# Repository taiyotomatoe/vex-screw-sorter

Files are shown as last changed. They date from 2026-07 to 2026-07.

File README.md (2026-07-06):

# Automatic Screw Sorter for VEX Robotics
**An automatic screw sorter, designed for standard VEX screws of sizes 0.25" up to 2.00".**  
*Note: Other screws such as shoulder screws may not work.*

We all hate having to sort our screws manually, and no one puts the screws back in the right place. 

That's why I made this screw sorter, which works **without requiring a human operator** to manually place screws on the sorter - just dump your screws in the box, start the motor, and get it sorted automatically.

### Preview: 

### Features:
- Knob, to control the motor speed
- LCD Screen to display current speed + number 

# Make your own sorter! 
All files needed to build this project are provided in their respective folders. 

### PCB: 
(Kicanvas wouldn't work...) Routing is a bit of a mess. (I'm a noobie at this)




### Firmware: 
Arduinon code

### Bill of Materials
[Link](https://docs.google.com/spreadsheets/d/1GzJbDsBg9s3fJ3GwzlsMUPDhf9ZihwElanYWZgdYd-w/edit?usp=sharing)

- XL4015 DCDC step-down converter
- JGA25-370 DC Reduction Motor with Encoder - 12V, 280RPM
- LCD Blue Screen IIC/I2C 2004 5V LCD Module for Arduino
- Alps EC11E Rotary Encoder
- Arduino Nano Every
- Male to Female Jumper Wire
- 2pcs 902540 3.7V Battery LIPO Lipo Battery 800mAh Battery
- 1.25T-2A: Connector for Lipo Battery
- WAFER-PH2.0-6PWB
- 2.54 Pitch PIn sockets 
- Magnets 5-pack

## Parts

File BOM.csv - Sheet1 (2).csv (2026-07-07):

Item Name | Qty | Price (total) (USD) | Item link | Notes
XL4015 DCDC step-down converter | 1 | $2.66 | https://ja.aliexpress.com/item/1005006127518056.html?gatewayAdapt=glo2jpn#nav-review | For faster shipping, I've ordered a different one.
JGA25-370 DC Reduction Motor with Encoder - 12V, 280RPM | 1 | $5.00 | https://www.amazon.co.jp/-/en/JGA25-370-Reduction-Encoder-Measurement-Strong/dp/B0BBT1Q1L7?th=1 | -
LCD Blue Screen IIC/I2C 2004 5V LCD Module for Arduino | 1 | $4.31 | https://www.amazon.co.jp/KKHMF-LCD-%E3%83%96%E3%83%AB%E3%83%BC%E3%82%B9%E3%82%AF%E3%83%AA%E3%83%BC%E3%83%B3-2004-%E3%83%A2%E3%82%B8%E3%83%A5%E3%83%BC%E3%83%AB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 | -
Alps EC11E Rotary Encoder | 1 | $3.39 | https://www.monotaro.com/p/5019/9653/ | -
Arduino Nano Every | 1 | $3.32 | https://ja.aliexpress.com/item/1005009007048978.html?curPageLogUid=Z3lVB11il7dK | -
Male to Female Jumper Wire | 4 | $1.27 | https://ja.aliexpress.com/item/1005006616309305.html?curPageLogUid=7d3j23TrAWTj | 10cm should be sufficient
# 2pcs 902540 3.7V Battery LIPO Lipo Battery 800mAh Battery | 1 | $8.01 | https://www.amazon.co.jp/-/en/2pcs-902540-Battery-800mAh-Drone/dp/B0GGHPSYZ7 | First time working with batteries - not sure if this is the right kind
1.25T-2A: Connector for Lipo Battery | 2 | $0.01 | https://jlcpcb.com/partdetail/BOOMELE_Boom_Precision_Elec-1_25T2A/C10819 | Assembled by JLCPCB
WAFER-PH2.0-6PWB | 1 | $0.12 | https://jlcpcb.com/partdetail/XUNPU-WAFER_PH2_06PWB/C3029444 | Assembled by JLCPCB
2.54 Pitch PIn sockets - | 1 | $3.33 | https://ja.aliexpress.com/item/1005007987705629.html?curPageLogUid=CK0XiXW3Ev6p | I will buy a quicker shipping option one.
Magnets 5-pack | 1 | $5.58 | https://www.migros.ch/en/product/721586900000 | There are definitely cheaper magnets - These are the ones I have currently. (and fit the dimensions of the design

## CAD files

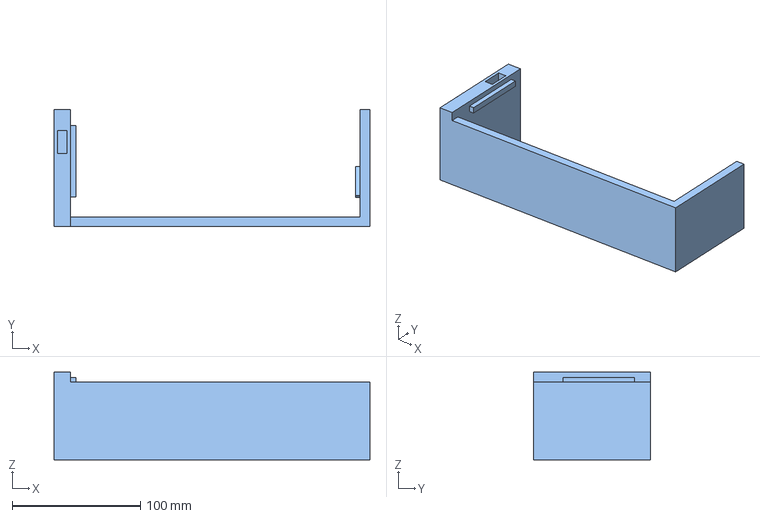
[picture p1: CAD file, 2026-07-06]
CAD/Individual COmpoents/Containers_Outer (4).step
246.4 x 91.4 x 68.6 mm

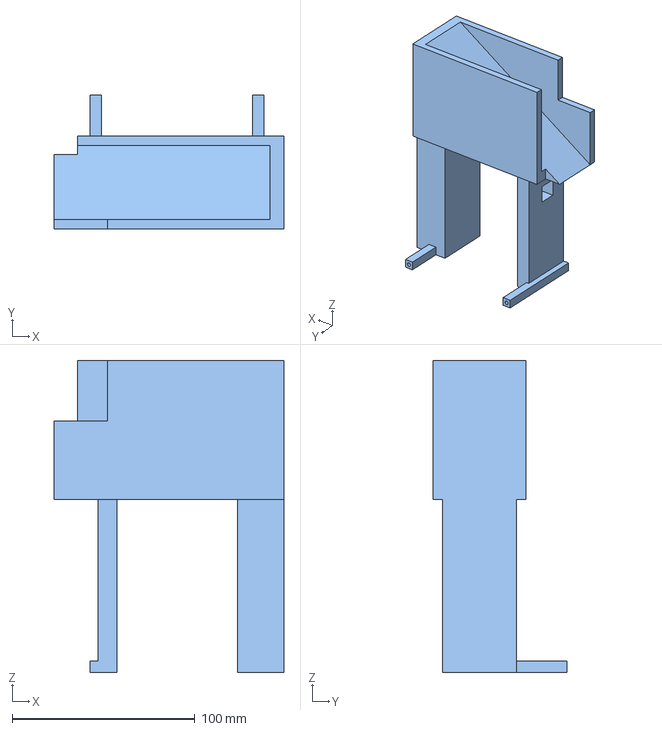
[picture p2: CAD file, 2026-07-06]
CAD/Individual COmpoents/Box.step
125.7 x 73.1 x 170.8 mm

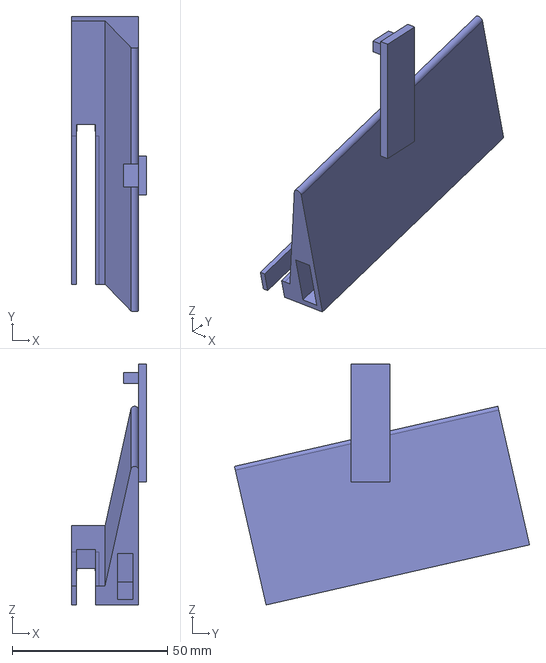
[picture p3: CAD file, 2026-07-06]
CAD/Individual COmpoents/loader_p1.step
24.2 x 95.1 x 77.7 mm

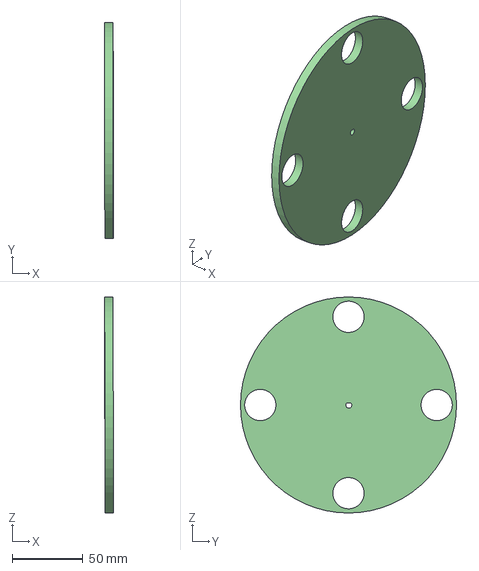
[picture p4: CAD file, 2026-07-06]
CAD/Individual COmpoents/Wheel.step
6.00 x 152.4 x 152.4 mm

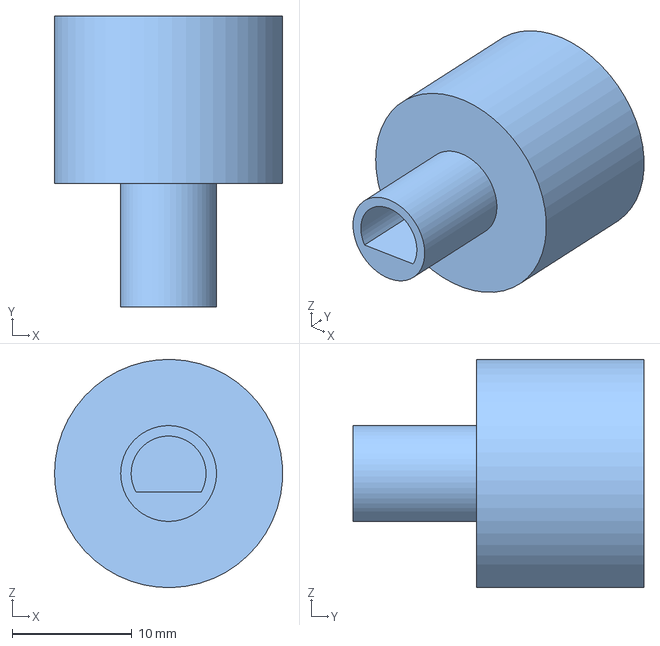
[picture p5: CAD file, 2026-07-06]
CAD/Individual COmpoents/Knob.step
19.0 x 24.3 x 19.0 mm

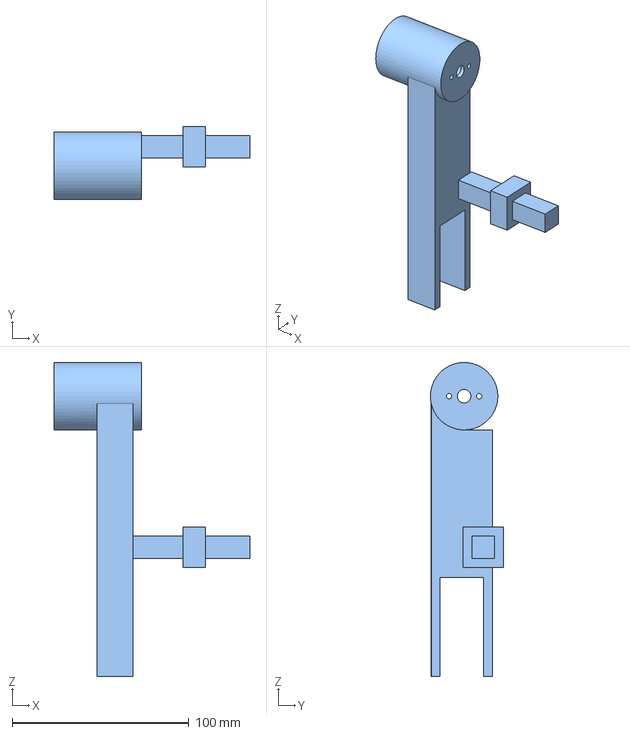
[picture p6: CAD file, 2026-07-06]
CAD/Individual COmpoents/motor holder.step
110.6 x 41.4 x 177.4 mm

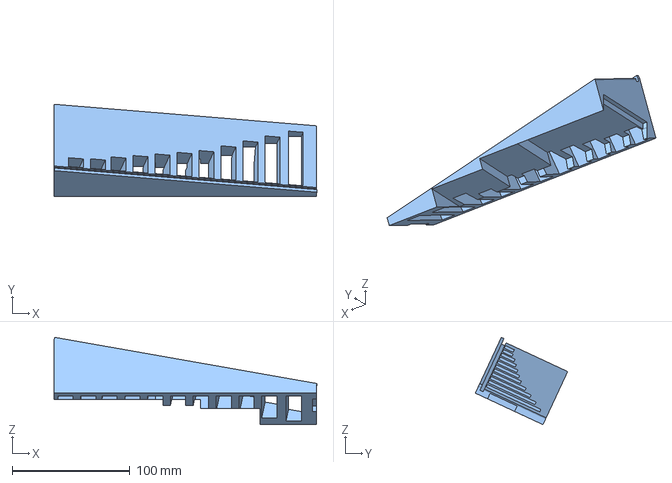
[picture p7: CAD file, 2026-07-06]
CAD/Individual COmpoents/Sorter.step
223.6 x 78.6 x 74.3 mm

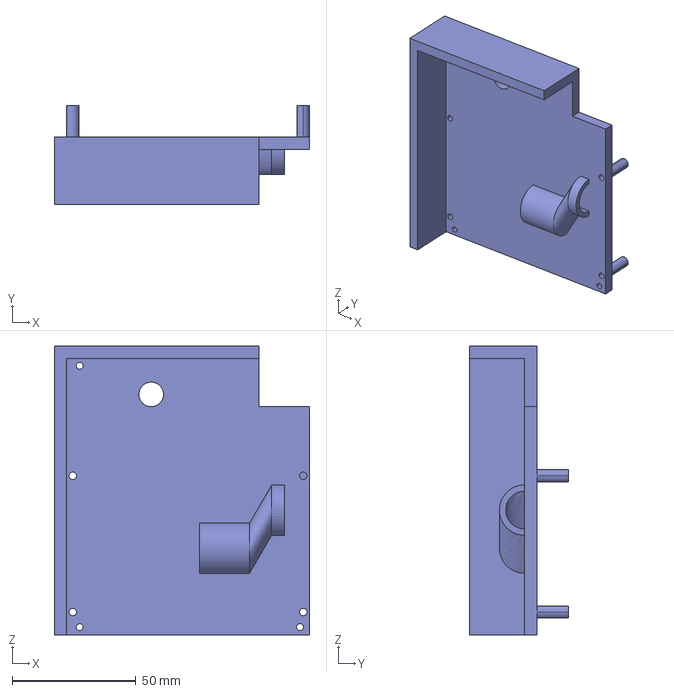
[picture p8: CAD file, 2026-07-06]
CAD/Individual COmpoents/PCB Cover.step
102.9 x 40.1 x 116.6 mm

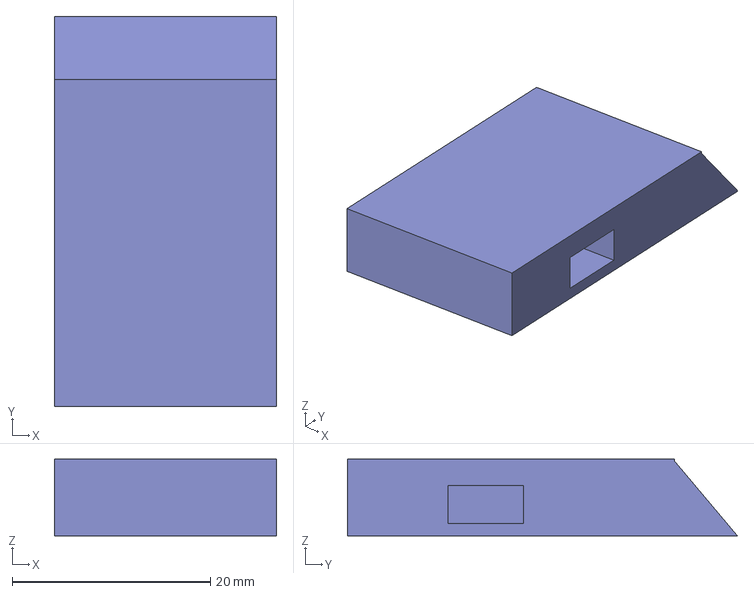
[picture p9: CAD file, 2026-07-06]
CAD/Individual COmpoents/Hook.step
22.5 x 39.4 x 7.76 mm

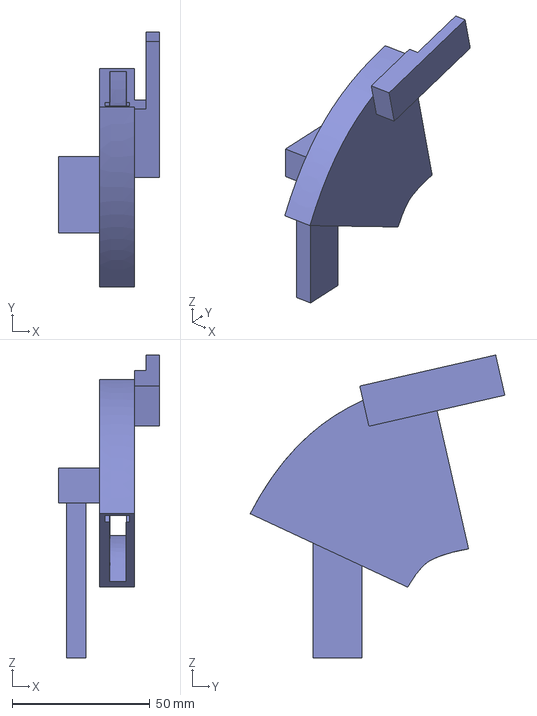
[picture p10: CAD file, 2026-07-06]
CAD/Individual COmpoents/loader_p2.step
36.7 x 92.6 x 110.1 mm

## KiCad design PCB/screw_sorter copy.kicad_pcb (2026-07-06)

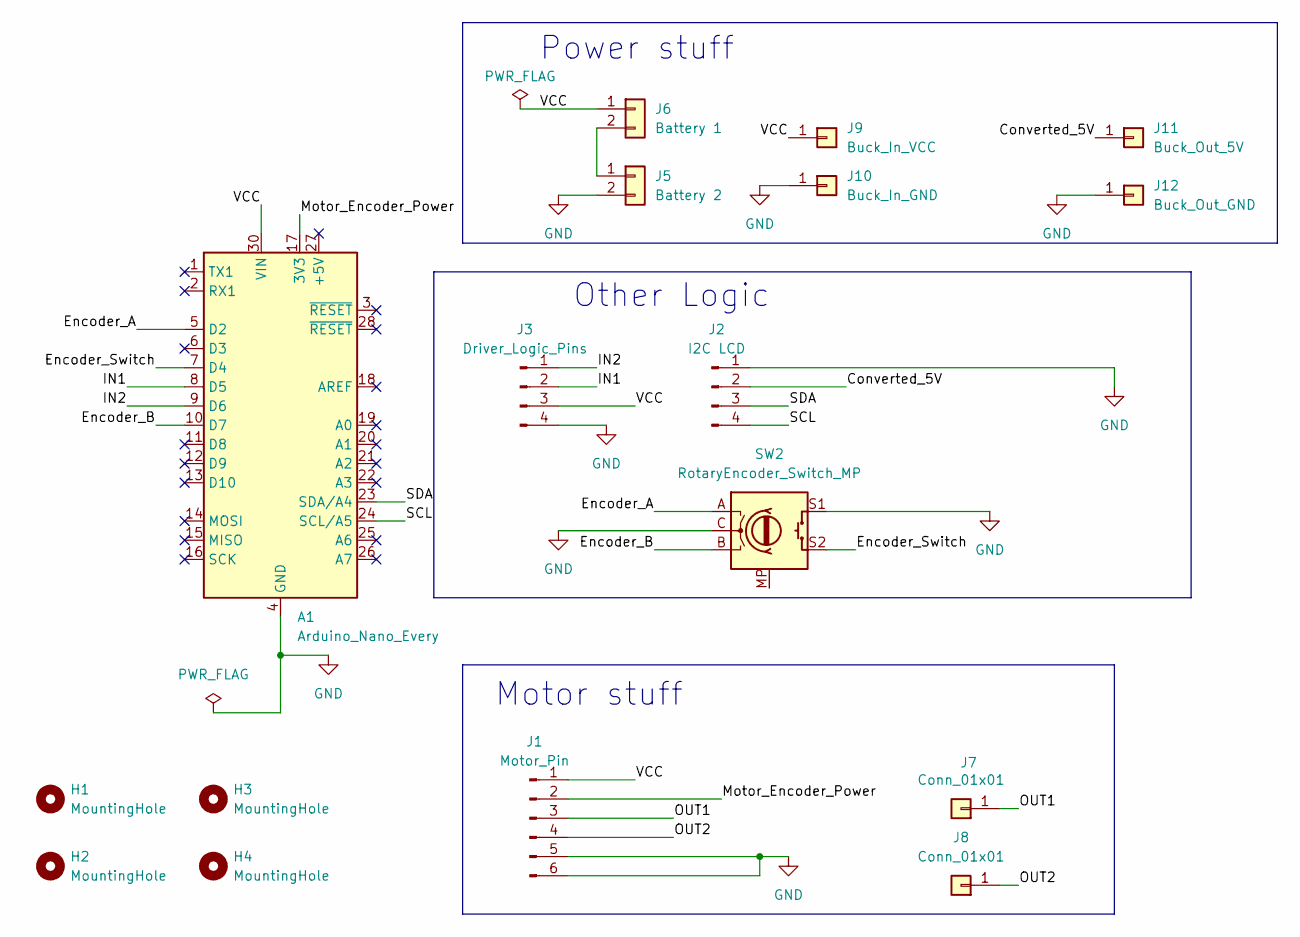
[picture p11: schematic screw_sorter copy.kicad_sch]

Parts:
A1: Arduino_Nano_Every; Arduino_Nano
H1, H2, H3, H4: MountingHole; MountingHole_3.2mm_M3
J1: Motor_Pin; WAFER-PH2_0-6PWB
J2: I2C LCD; PinSocket_1x04_P2.54mm_Vertical
J3: Driver_Logic_Pins; PinHeader_1x04_P2.54mm_Vertical
J5: Battery 2; 1_25T-1-2A
J6: Battery 1; 1_25T-1-2A
J7, J8: Conn_01x01; PinHeader_1x01_P2.54mm_Vertical
J9: Buck_In_VCC; PinHeader_1x01_P2.54mm_Vertical
J10: Buck_In_GND; PinHeader_1x01_P2.54mm_Vertical
J11: Buck_Out_5V; PinHeader_1x01_P2.54mm_Vertical
J12: Buck_Out_GND; PinHeader_1x01_P2.54mm_Vertical
SW2: RotaryEncoder_Switch_MP; RotaryEncoder_Alps_EC11E-Switch_Vertical_H20mm_CircularMoun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

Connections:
/Converted_5V: J2.2, J11.1 (Pin_1_1)
/Encoder_A: A1.5 (D2), SW2.A
/Encoder_B: A1.10 (D7), SW2.B
/Encoder_Switch: A1.7 (D4), SW2.S2
/IN1: A1.8 (D5), J3.2
/IN2: A1.9 (D6), J3.1
/Motor_Encoder_Power: A1.17 (3V3), J1.2
/OUT1: J1.3, J7.1 (Pin_1_1)
/OUT2: J1.4, J8.1 (Pin_1_1)
/SCL: A1.24 (SCL/A5), J2.4
/SDA: A1.23 (SDA/A4), J2.3
/VCC: A1.30 (VIN), J1.1, J3.3, J6.1, J9.1 (Pin_1_1)
GND: A1.4 (GND), A1.29 (GND), J1.5, J1.6, J2.1, J3.4, J5.2, J10.1 (Pin_1_1), J12.1 (Pin_1_1), SW2.C, SW2.S1
unnamed: J5.1, J6.2

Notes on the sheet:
Motor stuff
Power stuff
Other Logic

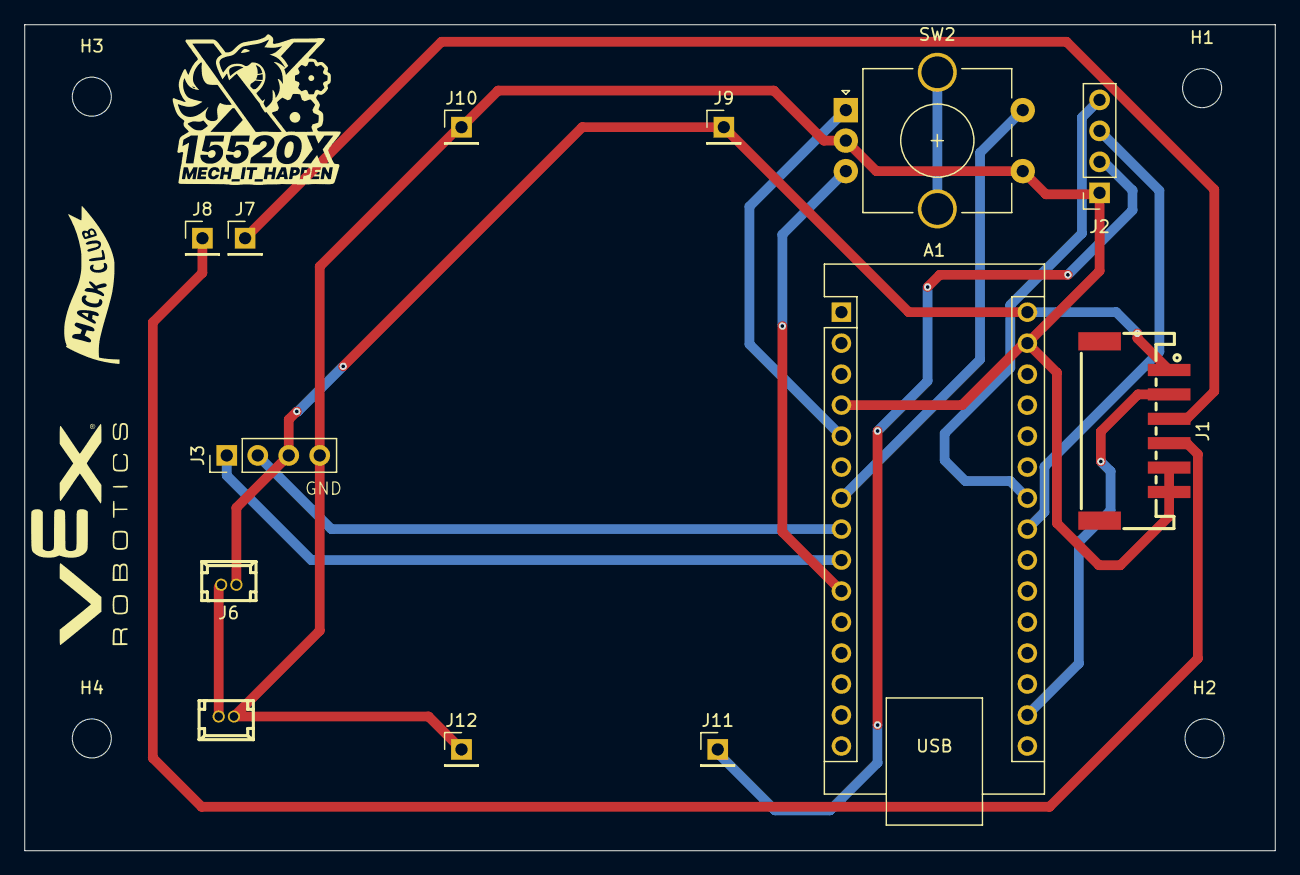
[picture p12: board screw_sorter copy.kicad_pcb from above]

Board: 2 copper layers, 102.5 x 67.7 mm, 17 parts (0 on the bottom side), 14 nets.

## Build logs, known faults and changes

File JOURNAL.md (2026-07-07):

# Devlog: 
**11h worth of work was done on Fallout. (I didn't submit there, as I didn't finish the project.)
More accurate time logs on Lapse/Hackatime.
Fallout Journals are under the journals I did for outpost.** 
### I also had to transfer the images from fallout... I did this manually so it may look messy at times

# 3 July: 
Finished the schematic... 

I finalized the list of the main components for the PCB: 
Rotary Encoder (leftover. from Blueprint)
LCD 
12V Motor (with encoder)
Arduino Nano. 

I found out that I most likely shouldn't power tehse components with the arduino's power pins, so I did some research on voltage converters: 
buck converter vs linear regulator.. .

I also had to do some digging around to find the pin headers for the motor. This motor is one my school had lying around, and has a 2.00mm pitch. I decided to have this assembled by JLCPCB. 
I had difficulties finding a suitable footprint/3d model for these components, so I found the JLCImport plugin, which made my life so much easier by letting me import footprints from within KiCad.
JLCImport Plugin 
(yes I could've just used the default KiCad ones, but this also applies to other components/projects)

I also need to find a suitable battery to power this project. It could be done using either. a LiPo battery or a power bank. I will do further research on this. 

#2: 
Went back to the CAD. I have to fix an issue on the main sorter where the bigger screws would slide off the bottom - Hopefully by making the part the screw body rests on a bit lower, there should be less bumps to throw the screws off course. 
I also need to change the wheel a bit, so that the magnet fits well - I think it was too wide, but I don't have any calipers with me - I will test this while the thing is printing and stop it when fit. 

I realized I made another dumb mistake, and wasted some more filament. I printed a "testing" patch to waste less filament, with 5 different sizes, so I could see which one would work best, before printing the actual wheel *again*. 

I'm trying to think of ways to secure these two in teh same posiition relative to the sorter each time, but I'll have to test this once it's printed. 

Back to electronics research - not really sure whether the DRV8833 that I'm planning on using for motor control is suitable, because my motor's stall torque is 2A and the DRV has a max current rating of 1.5A. I'll test this out. 

A friend suggested using the DRV8871 instead, which seems to be the better option. 

#3/4: Tested out the new wheel thicknesses, and I have a size that alows the magnet to be friction fit well. I will print this final version now. 

I also decided on a [lipo batery ](https://www.amazon.co.jp/-/en/Battery-Rechargeable-Terminal-Bluetooth-Electronics/dp/B0G2MJ5YLF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)
and addded it to the circuit.  

I'm wondering if I can/should power both the arduino and the motor directly from the battery, as I'm worried of a current spike or something when the motor starts spinning. 

Time spent (total for today): 3h30

# 4 July

Looking at the buck converters, I just cannot find the footprint for them. I think what I'll do is I'll estimate the destance between the pins, and then bend the pins on the pcb when soldering the buck converter on. (unless someone warns me to do otherwise)

For this one, I'll go with 21mm and 52.7mm apart. 

Time spent: 1h50

# 5 July: 

I'm reprinting the sorter again - hopefully printing it the other way will make it work better. It seeesm that printing the sorter upside down makes the face less smooth because of the supports, which makes it work less. 

I'm also just going to use the 3d model to space out the buck converter pins out correctly. Hopefully this is a precise enough method. 
I think this turned out ok. This better work.. 

I've been running into more issues to do wiht pin spacings and not finding their values anywhere, and I'm slwoly makign progress. I've been measuring the 3d models that I found of the components, so the pin distances shoudl be correct, assuming the 3d models were correct. 

I think I have the layout I want (haven't done the routing yet), and I will import this into Fusion and design an enclosure for it. 
This is the idea for now: 
I am slightly worried that the potentiometer will be difficult to control because of its position as well as the plastic used to support it being light and probably prone to sliding around. I might change the pcb just to make the potentiometer higher up, depending on costs, and I'll experiment with the box as welll to make it less prone to sliding around. 

I made a little mistake not setting the clearances before routing the traces... Hopefully the clearances I calculate aren't much more than what I currently have. 
Looks like it's fine. 
I moved onto adding graphics on the silkscreen, then realized all my 3d models were gone, for some reason... 
Back in business. 

Time spent: 3h30

# 6 July: 

#1: 
To make it easier for the user to turn the rotary encoder, I think I should make a knob for it. 

#2: 
Wrote some code for the LCD screen that'll be used. The encoder code should work, I already worked on it a month ago. 
I used the map function to map encoder values to 0-155, because I don't want the motor spinning at full speed (255). 
I also learnt how the I2C comm works, and that it's a form of serial communication alongside UART (the one I was familiar with), and  others. 

#3/4: 
Some more work on the CAD - changing hole sizes to fit better... etc
Rendered the Screw Sorter - the final printed verrsion probably won't look as vibrant, but I think it looks alright for now. 

Time spent: 2h55

# automatic Vex screw sorter — Journal Export

- Exported at: 2026-07-07T04:16:02Z
- Project ID: 1106
- Entries: 8

## Entry 1
- ID: 8177
- Author: tomato
- Created At: 2026-05-20T16:42:01Z

### Content

(logging this 3 days later, was busy) 
this is my first journal, which will also serve as part of the readme, because I’m writing my idea of what this project will look like. I did previously work on this project without logging it, but I have many more improvements to make - I’ll mention the first one in a second. 

In Vex robotics, we all use screws. However, it’s easy to throw the screws we didn’t use into a random box and forget about putting it bac where it was. 

My screw sorter is an automatic solution to this problem - just dump all your screws in a box and it’ll automatically sort them by size. 

Other designs sort the screws, but still require a human operator to manually put the screws in place. Example: 


my goal for this project is to make the process fully automatic. 
It will use: 

- dc motor, (battery)
- switch to turn it on and off,
- and other features i decide to implement down the line.

I might make a custom pcb for it if I decide to add more parts/to make it look nicer. 

This design by Christopher looks interesting, using magnets to pull the screws up from the box. 


I already have the bottom "sorting part" - made previously. 
The way it'll work is that the screws in the box area will get picked up by the wheel, which has magnets inside. This will then bring it up to the dispenser part, where it'll be directed into the sorter area. 
I am thinking about what would happen if a long screw comes along and it’s upside down. 
I've also found it difficult making a box design that doesn’t interfere with the wheel. 


I also need to make the box inclined so that the screws bunch up near the bottom of the wheel. 

I added a “hook” which would theoretically detach the screw from the magnet (i also made the hole for it)
and a cover to keep it from falling out. 
In hindsight I don’t think the “hook” needs to be shaped this way.




there is a rail for the screws to slot into place in the round part. 

tomorrow, I will (NOT BECAUSE I WAS TOO BUSY)
- work on making the box work,
- attach the new parts (the hook and the cover are currently floating)
- add a shaft/mounting hole for the wheel to spin

### Recording Links

- https://lookout.hackclub.com/api/media/9636e65d-2c7b-4c0e-94a6-4ae4e1f16784/video.mp4

## Entry 2
- ID: 9653
- Author: tomato
- Created At: 2026-05-27T13:32:42Z

### Content

today, I mainly focused on the box part. 
previously, the box was just a flat box, so once there weren’t enough screws, the magnets wouldn’t pull the leftover screws that were too low or too far to get picked up. 


I therfore made the box inclined, so the screws would naturally tend to the wheel. 

I also had to maek sure that it wouldn’t interfere with the other parts of the sorter and hit other screws. 



i then realized how dumb i’d been to just have a box enclosing the whole thing: the screw would just get stuck inside. 🤦




I therefore made a slit for the screw to go through. 
this may cause rpoblems down the line, wiht screws falling out from the slit, especialy the smaller screws, but I want to test this version first and then come up with solutions. 

NExt I worked on teh hook a little bit, making it a bit less complicated. 
i also attached as one body like this, although I mgiht need to make some changes when printing this as i can foresee the need for some supports. 
I’ll go for this for the moment because I want to test this section, without having to figure out a complicated mechanical attachment system (That’d be more efficient/refined, so work for another day)


this is the current result. 


i also did some cleaning up, renamign the bodies. 
I should rename the sketches one day too.  


the takss now are: 

- make a drive shaft hole in the wheel, (+ an attachment) so that the wheel can be spun by a motor 
This’d allow me to test the loading section (fig.the image above)
I will test this on a breadboard for the moment, I am also considering implementing other components on a PCB.
- make a support for the box (it cant float unfortunately)
- figure out a support for the main sorter: 
I previously had a design which worked, but it was a bit clunky and required some taping. 
I will therefore rework this.



I also want to learn how to deal with sketches in fusion360, such as when I insertt a new component and then want to edit a previosu sketch with the new component in mind: (the new component doedsnt show)

I wasn’t able to find an answer, and I have asked some of my teachers.

[Continued on the next day, 26 May]: 

I briefly worked on the README, learnt a bit about how to use Markdown. 
I need to find what motor I’ll be using, so that I can: 
1. Put it in the 3d model and design accordingly
2. (Order if needed); assemble the circuit for testing (RPM shoudln’0t be that fast)

Otherwise, I improved the body separation for the loader. This allows the parts to be tested individually, saving on filament/time. 
To attach the hook, I created a hole and will fit a bar into it, as seen in the images below. 
I also incorporated tolerances, which I will need to test as well. 











Below was my first idea at attaching the curved part with the first part of the funnel. 
This won’t work, and my current solution I have in mind is: 
hot glue the parts together
however this will make testing more inconsitent/harder in my opinion, so I will figure out a better way tomorrow. 





I also need to think about how to attach the motor to the wheel, as there are many parts around that miht interfere with the motor attachment. 

That’s it for today (and yesterday), next time (tmr hopefully) I will: 
figure out the body attachment methods
do some research on the motors/start designing the pcb???
3d print soon

### Recording Links

- https://lookout.hackclub.com/api/media/746643bf-e4d1-42b6-8ecd-86335d50c0c6/video.mp4
- https://lookout.hackclub.com/api/media/720516d4-a807-4749-aefb-02b7c3763dcb/video.mp4
- https://lookout.hackclub.com/api/media/73e45309-c194-4816-9717-e51777492c30/video.mp4

## Entry 3
- ID: 10525
- Author: tomato
- Created At: 2026-05-30T21:47:17Z

### Content

### 30 MAY: the loading part has been printed and is being tested! 

Firstly, I added some supporting pillars for the box. This can however be replaced by a book or something for testing. 


i also found a DC motor to use - it’s just a 12V motor that I have lying around at the moment - that’d be the easiest to use for now. I make the shaft hole for it in the wheel. 

I should, in the future, allow the wheel to be attached to the box, so the distance stays constant (easier for end user)
But I will do this after I figure out what other parts I need and where to put them, like the battery and cables.. 




The sorting part requires the main sorter and the containers that will store the screws after they’re sorted. image: 



the mian challenge was having the containers not hit the screw sorter, as the top sorting bit has to be slanted to work properly (the screws tend to get stuck if it’s not inclined)

I first made the other slot for the screw sorter to be held in place. 





I had to make some minor adjustments here to make sure the sorter would hold in place, using the cross-section analysis tool in Fusion. 

But then I realized I could extend this hole so that it goes further down, giving the containers more space. 

This wans’t enough for the containers, however, so i redesigned them (based off the projections of the old design) to fit more nicely with the main sorter. 





The sorter, along with the containers, are now ready to be printed. I’ll only print one for now to not waste too much filament. 

**[SECOND Recording]**
I came back and worked on the wheel. I firstly added a holder for the motor. 



The wheel should be at a set distance from the box, so that it works well; 
The obvious solution is to. have the box and wheel be one big body. 
However, I want to keep the parsts of this project modular, so that they can be 
a. printed easily
b. tested easily individually. 

Therefore, I thought of making the wheel part attach onto the box, like this. 
I now realize that this will probably cause the motor to fall over in the direction of the wheel, due to the weight of the motor. I can, however, just put a book under to keep it balanced. 



I also attempted to run some stress tests (simulations) on the system, to test the durability, especially of the shaft that holds the motor holder and the box together. 
However it turns out it’s a bit complicated, and 3d printers don’t completely fill up the bodies with filament anyways, so it’d be underweight by a percentage. therefore running tests, even if i could, would most probably overestimate the strength of this part. I’ll try the simulation feature out one day on another project. 


NExt I decided I want to test the loader part. I made it so that the loader can slot into the sorter holder, so that I can test it individually. 





I also split up the loader into two parts, so I can test those individually, and added a coupling attachment. 



I am now going to test these parts of the system, and hopefully they work! 
the last step is 3d printing them, for which I luckily have a 3d printer for at school. I put the file into bambustudio and I am now going to wait ~3 hours for this to print. Hopefully it works! ~~(Now time to stop procrastinating and do my homework…)~~


**[3rd recording]**
So I spent some time testing the loading mechanism that I printed off. Despite some difficulties when removing the supports that came with the print, resulting in me cracking a bit of the plastic, it seemed to work well. 
The screws occasionally require a little nudge, but I can tolerate that for the moment. I haven't tested the first stage yet, as I didn't print it. 

I tested this using the old screw sorter design that I had worked on previously to fallout - it's a bit different, thus why the screws are falling out in the image - the new version should be better. 
I already know that the sorter works, so I won't be prioritizing its testing, yet. 
IMG_3743.HEIC
**Screws were getting stuck due to the printer support filament being hard to remove fully. **
IMG_3739.HEIC

[4th Recording]
I also printed the first stage of the loader. This is when I realized how small the parts physically are, compared to what they looked like in the CAD. I will pay more attention to this n the future. 
IMG_3747.HEIC

I therefore added 2 things to the design of the motor holder: 
- More support for the motor holder
- A stopper so user can attach it to the box easily



### Recording Links

- https://lookout.hackclub.com/api/media/35a3cb54-dcf8-4e49-94c5-097720b6a71f/video.mp4
- https://lookout.hackclub.com/api/media/59da71e0-00d0-4ba8-af40-d77a6ec7c561/video.mp4
- https://lookout.hackclub.com/api/media/ad360f85-8680-47f5-b002-0fccaf02da5a/video.mp4
- https://lookout.hackclub.com/api/media/3a4a85cf-fa2a-4836-8156-b03425d2ca2f/video.mp4

## Entry 4
- ID: 10527
- Author: tomato
- Created At: 2026-05-30T21:54:26Z

### Content

**[From 27 May - Wasn't logged for some reason]**

I started this screw sorting project before fallout. Therefore I already had some designs (which I wasn't completely satisfied with) started. To further integrate each body within the system, I decided to bring over the holder for the screw sorter, so that I could attach other parts of the whole system to it. 

It's basically just a rectangular holder for the actual screw sorter body. 

I didn't take screenshots but I had difficulties with extruding (removing) some of the old parts of the container, but I was able to do so, and make a extrusion and a hole so the sorter would be held by the container. 





### Recording Links

- https://lookout.hackclub.com/api/media/bf9a2d16-2cd5-457c-9a67-b81407850010/video.mp4
- https://lookout.hackclub.com/api/media/bd9e2ee6-111c-4b4c-8b87-b80df1ba6046/video.mp4

## Entry 5
- ID: 11712
- Author: tomato
- Created At: 2026-06-04T21:20:45Z

### Content

# Small CAD Fixes + Starting Electronics!

So for this project I decided to use a motor with an encoder. I want this project to be a bit more complex than just a singular dc motor spinning while the switch is closed. 

After my research, in this circuit, I want:

- an LCD screen, which will display: 
Motor encoder values (probably number of rotations or something)
+Whatever i want it to display
- A motor with an encoder
- Potentiometer - to control speed

I will now make the pcb/schematic for this (hopefully successfully)

## CAD Cleanup

Before that, a few things to clean up in the CAD: 

Here I added a holder for the motor to keep it in the right place. I might add one on the other side as well. I hope I didn’t make it too small. 



I then realized I should probably just make a proper motor mount. So I made one. 
Therefore I got rid of those two things on the back because that’d make it impossible to put the motor in 🤦
The gap between teh wheel and the motor is very thin, so I hope that the mount isn’t too thin. To make it a big stronger (I hope), I attached it all the way around the motor, like this. 





I’ll try to get the wheel and this holder printed tomorrow - I’ll put the magnets in and I’ll then plug in a motor and test it out. I really hope it works. 

i hawd to make some minor adjustments to the motor mounting holes after re-consulting the datasheet. 

## Electronics

getting started with the electronics: 

- I searched for a potentiometer, but didn't really know what to look for - will do some research tomorrow and come back to this



i was reading the datasheet (hopefully the right one - the image didn’t look the same as the one I have..)
So I need to decide a microcontrolller that can handle both the motor and the lcd. 
Im hoping this means that the power in for the encoder should be 3.3V. 




Found an example circuit. the colours are a bit differnet but. 
Looks like encoders have two signal outputs: i don’t fully understand why, but it has to do with this thing being a "quadrature encoder", I will do some more research on this tomorrow. 

i’ve been trying to find the correct size for this connector, so that I can use the correct footprint in my pcb. unfortunately I cant so ill just measure it tomorrow when I have a caliper. 
also for some silly reason I imported the arduino nano symbol + footprint only to realize that Kicad already has it. Duh. 



I’m not very experienced in electronics in general, so I will do some testing of the LCD screen on its own. 
Additionally I need to figure out a way to get the footprint/symbol for the motor connections. THis may mean I have to make it myself in the symbol/Footprint editor - I’d just like to confirm this with a friend. I also need to learn more about potentiometers and what values I should be looking at when deciding one. 

Depending on this testing, I can find out how many pins all these components will need, and I can choose a suitable microcontroller for it. The idea is that this PCB will fit somewhere here, where the LCD screen + potentiometer can be accessed by the user easil.y 


**So to recap the next tasks are: **
- Print the motor holder + Wheel
- assemble motor + holder
- Test the wheel with a dc motor (no proper circuit/encoders yet)
- continue electronics when i get answers from my friend 

### Recording Links

- https://lookout.hackclub.com/api/media/78474f9b-a5ce-4b02-bfe3-06e9b631c07a/video.mp4

## Entry 6
- ID: 11924
- Author: tomato
- Created At: 2026-06-05T19:41:12Z

### Content

# [Electronic research continues! +some cad ]

I made the other holes for the wheel, so that I can print it and test it with the magnets. 

I’m a bit worried about the wheel and its rigidity - this might be too thin. 



I measured the dimensions of this area (the box, under it) - this is probably where the PCB will go. 
as well as the LCD. 



I’ve been looking for potentionmeters - the first one I found doesn’t seem to have a datasheet. Will need to do more research tomorrow. 

I did some research on the LCD Screens, and it turns out the easiest way is to use an “I2C Backpack module”. I Found one of these lying around, so I can put it in my design. 



I will connect this via jumper wires to the PCB. 

I also tried to do some soldering. 
(second recording - forgot to take pictures unfortunately)

In this project, I need to solder the I2C backpack module to the back of the LCD screen, as well as any other soldering. 
A main problem I had was that the solder was sticking to the iron tip, without sticking to the wire I was trying to attach. I followed a couple of tutorials, and it said I should use flux, but it didn’t really help - a teacher I asked suggested that it might just be a problem with the tip. 

Therefore I wasn’t able to test the LCD Screen today - I’ll get back to it soon. 

Reading the motor datasheet further: 

I understand that the stall current is the highest current my circuit should be able to handle. 


For the electronics, I also need to find a battery that I can use. 

The motor uses 6-12V, which the arduino doesn’t seem to handle. I will therefore power this, and the mtor driver - which is needed to control the motor’s speed and direction - with a 9v Lipo battery (probably)

I will use a school project as an example, and therefore I will use this motor driver: 

I will get the breakout board version to make it all easier to assemble. 
I just need to find a suitable battery and the symbol for the driver so I can finish the schematic. 

I also sent three parts to print, so that I can test them later on. 



I printed a reduced version to preserve filament and time. 
I just need a way to test if this holder works.



Tomorrow I will: 

- Assemble + Test the parts
- print the remaining other parts
- Further soldering practice/try to solder the lcd once I’m ready

### Recording Links

- https://lookout.hackclub.com/api/media/c207e46e-adea-45e1-84eb-20bf3dbde5a0/video.mp4
- https://lookout.hackclub.com/api/media/583055d6-78fb-462f-9d47-6aa88ca697bb/video.mp4
- https://lookout.hackclub.com/api/media/bb4beb66-4c9e-4640-a470-8d2fdce642ae/video.mp4

## Entry 7
- ID: 12122
- Author: tomato
- Created At: 2026-06-06T20:21:38Z

### Content

# [Testing -  A success! + Relevant Fixes/Improvements]

I go to test the parts I printed earlier, to great success. 
Removing the supports took a while, because they were in small holes. 

I didn’t have any better tools available so I had to use this bit of my nail clipper to take out this tiny support. 


The Loader part1 worked 95% of the time, and it only had occasional screws getting stuck, especially the smaller ones. Hopefully this issue resolves itself when I test this with a motor. Otherwise, a solution would just be to maybe filet/make this gap a bit wider. 



The two loader parts integrated well with eachother, which I’m very happy about. 



the motor hub worked well as well - it fit well. 



the wheel needs to be improved, however, as it had two issues: 


1. too thick: the magnet was to thin for the wheel, so the screws would get stuck in between the wheel and the magnet. I will simply make the wheel a bit thinner. 

2. 3d printing tolerance
I for some reason forgot to add a slight clearance: i couldn’t put the motor shaft into the wheel. this should hoepfully be an easy fix. I wonder if there’s a feature in Fusio360 that allows me to replicate a sketch but with a tolerance. 

# Fixes!!

I started by making the wheel thinner, according to the magnet’s dimensions (measured properly this time)





I added clearances (Not “tolerances”) to my motor shaft extrusion, using the offset tool (thank goodness I found out this exists)

I also made this part a bit smaller to accomodate for the motor irl (i stopped the print a bit early, so the current version I have looks a bit too small, but measurements tell me I should do this)





I also made the gap for the loader part 1 marginally bigger. This should hopefully help with the jamming issue. 

Later today, I will send this to print, so I can have the whole non-motor part working. 



Tasks now: 
- Keep printing + Testing parts
- Electronics research + design!!!

### Soldering practice

I did some more soldering practice. (Image - pins on the left)

I used some more flux this time, and I got *some* decent connections. I also tried de-soldering, but not to much success. 




Slightly foolishly, I decided to start soldering the LCD backpack module on. It therefore got attached a bit slanted - not a completely detrimental issue (hopefully), but I could’ve done with some more practice. 

### Tasks for tomorrow:

- Test the new parts
- Continue the electronics research/schematic

### Recording Links

- https://lookout.hackclub.com/api/media/04125ba0-8b23-43db-af39-6a143a385a31/video.mp4
- https://lookout.hackclub.com/api/media/499a8498-faea-4911-88d7-8f753571642a/video.mp4
- https://lookout.hackclub.com/api/media/ff4e93d6-3229-4520-bc0c-04b9cc93bf62/video.mp4
- https://lookout.hackclub.com/api/media/b2e061b7-8a2d-41b6-ae25-8dd2f6ac378f/video.mp4

## Entry 8
- ID: 12359
- Author: tomato
- Created At: 2026-06-07T19:47:51Z

### Content

# [Electronics breadboard testing / software]

So today I’m going to learn a bit more about how my circuit will work - the folllowing components will be used

- Arduino Uno (instead of nano for now, for simplicity and availability)
- potentiometer (dont have the name yet)
- 9v battery
- dc motor (12v - jga25-370)

the first step would be finding out how the encoder works (how to wire it)

I found a the datasheet (screenshot later) and got this circuit. 


### Arduino Coding


For background, I only know some basic python. 

i just found out that variables have to be declared globally (Im pretty sure) before being formally given a value, unlike in python where I can just define it at any moment. 

Trying to figure out the logic of the encoder: how is the “GND” pin the encoder pinC??? 


I am just so confused here. I am following a tutorial of some sort, but using it as a guide. 



Below is my own code. 
I made some changes, notably to the result of the logic, because I want to use these values to translate to outputs for the motor to use. 
Turning clockwise would increase the position -> the speed, and encoder position of 0 means that the speed would be 0.



I sometimes get these readings, , even though I’m only turning it in one direction. I’m guessing this is due to inaccuracies in the encoder module. 


The next step is connecting the motor to the circuit and using these encoder readings as inputs for the motor. 

So I couldn’t find a suitable power supply for the motor - I implemetned the logic I wanted, and I will test this later today. (I need to add the motor controller pins/code as well, but I’d find it hard to test without the motor spinning too)

I used the map() function to map the encoder’s values (capped at 20 - more on this later) to a range between 0-255, to represent the duty cycle of the pwm signal, which will be used to control the DC motor’s speed.



I can’t think of how to cap the encoder position at 20, however. I need to find a solution. 


I was planning on controlling the motor speed using these encoder values, 
but I unfortunately don't have a power supply at the moment, so I couldn't test the motor 
(I had the plug, just not the EU adapter)


Next Tasks: 
Get a power supply and test the motor
Continue testing hardware
Find a better ptentiometer and put it in the schematic

### Recording Links

- https://lookout.hackclub.com/api/media/ef5baa33-2fd6-419d-9db0-e3fa48e674f2/video.mp4
- https://lookout.hackclub.com/api/media/e9ec7b1f-99b9-43f7-a91f-5863b54d79d1/video.mp4

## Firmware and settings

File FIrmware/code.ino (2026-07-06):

#include <Arduino.h>
#include <LiquidCrystal_I2C.h>

// This code currently only prints the speed out, but is easily modified to control the motor
// The LCD Screen isn't programmed fully yet - SOON TBC
// I'll do this asap - I want to prioritize getting the PCB reviewed however. ar
int en_a = 5;
int en_b = 7;

int en_a_last; 
int en_a_value;
int en_b_value;
int encoder_position; 

int motor_duty;


LiquidCrystal_I2C lcd(0x27, 20, 4)


void setup() {
  pinMode(en_a, INPUT);
  pinMode(en_b, INPUT);
  en_a_last = digitalRead(en_a);
  Serial.begin(9600);

  lcd.init(); 
  lcd.backlight(); 
  lcd.setCursor(5, 0); 
  lcd.print("Sorting Screws...")
}

void loop() {
  en_a_value = digitalRead(en_a);
  
    if (en_a_value != en_a_last) {

      en_b_value = digitalRead(en_b);

      if (en_b_value != en_a_last) {
        //therefore encoder a switched values first
        if (encoder_position != 21){
          encoder_position++;
        }
        else if (encoder_position = 21) {
          encoder_position = 20;
        }
      }

      else {
        //other direction
        if (encoder_position != 0) {
          encoder_position--;
          
        }
        else {
          encoder_position = 0;
        }
      }

      Serial.print("Encoder Position: ");
      Serial.println(encoder_position);
      motor_duty = map(encoder_position, 0, 20, 0, 150);
      Serial.println(motor_duty);
    }
  en_a_last = digitalRead(en_a);
}
